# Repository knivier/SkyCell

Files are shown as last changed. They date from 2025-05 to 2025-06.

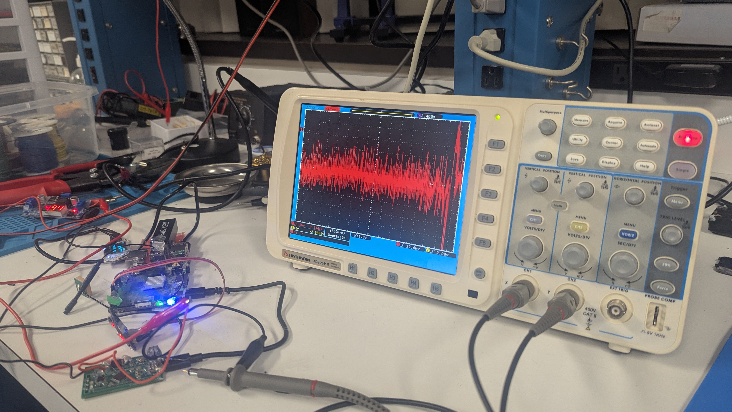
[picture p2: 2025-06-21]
project-images/prelaunch_night.jpg

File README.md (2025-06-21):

# SkyCell

#### The telecommunications solution on a balloon...for broke people alike.

This event was funded by the Apex event where we launched SkyCell on June 21st, 2025. It was the culmination of work from all of our teammates and over two months of planning (not to mention $400 in parts alone funded by Apex and the over $1200 in flight coverage as well).

## The Vision

Hurricanes, tornados, dust storms, and whatever other disasters wreck havoc on communications systems every year, risking lives. Technological dependency for communication has made telecommunication-based systems extremely important, and disasters pose a significant risk to that. 

Our team came up with the idea of SkyCell: A disaster-relief based telecommunications relief package/module that could be a backup incase primary communications systems fail.

## The Goals
1. Receive telemetry data in a JSON format from SkyCell when it is in the air
2. Be able to connect to SkyCell via a LoRA transceiver
3. Send and receive messages using SkyCell through meshtastic software 

## The Execution
### Planning
The initial plans were a basic CAD viewing of what SkyCell could look like along with a basic BOM. We knew we needed LoRA based communications, so we went with ESP-32s due to their relatively affordable prices (specifically, Heltec V3s). Pat also wanted to have SDR logging capabilities, so those components were added as well. We also got our own GPS module because we wanted SkyCell to be largely independent from the main balloon. 

For the main motherboard, we initially wanted to think about using a Raspberry Pi 5. However, it's a known fact that they aren't a great value, and a significantly better deal was a *Radxa Rock 5C*. This board was more efficient and more powerful than the RPi5 while also being cheaper (on amazon that is). 

For power, we initially thought about 4x AA batteries but later went with 8, then 6 for some redundancy. Energizer Li-Ion Ultimate's were chosen as Apex organizers mentioned they were one of the few AAs that supported as low as -40C temperatures. 

For software, we went with a modular design, choosing to implement features slowly as we coded our main board. Built in logging was very important as should SkyCell fail to send messages, we would want to see why. These were written on a local SD card in the R5C. 

We also wanted to implement a camera (you can see remnants of that in `code\kniv's testing`) and created a compression algorithm for that as well that could have sent images over LoRA theoretically. However, this was later cut out in the final planning stages due to the higher expenses.
### Building
The building stage took an additional two months. During this time, parts were coded, assembled, and soldered down. 
#### Launch Night Issues
When testing with battery power (attempting to send/receive messages on battery) and with using a DC current power supply (regulatable), we discovered that the DC buck converter was having issues catching up with 5V, especially when systems like GPS and radios started (see: `project-images\prelaunch_night.jpg`), which caused bootlock and SD card corruption issues. This led to us trying to give as much voltage to the R5C without frying it (we gave up to 5.2v on the DC-DC and supplied 12V at one point), and we also tried large capacitors (up to 10,000µF). We also tried using a custom DC-DC 5V stepdown from another 'Apexer' with no luck. We even used a oscilloscope (that was a new one) to find out voltage patterns and isolate the problem.

In the end, we needed to scratch the idea of having AA batteries and instead chose to have a power bank fitted. This would only give us up to 30min of time, but it was better than having a non-functional project as a whole. 

We also wanted to have some telemetry sensors like a BMP180 for barometric, altitude, and temperature, along with an AHT21 for humidity and more temperature. During the flight though, the BMP180 got fried and when the AHT21 was working, it was already too late to implement a UART based system to connect the Pico to the R5C.
### Launch Time 
The module was launched at around the afternoon and traveled for around two hours. We only received around 3-4 packets of data and were able to connect to the node quite far away (LoRA systems were set up back at the main site while the balloon was launched quite far north). 

## Review

### What parts would we use instead?
For starters, a significantly better DC-DC Buck Converter. The issues would have been fixed if we could give more power to the pi at certain points (ex at startup give the Pi 5V->5.5V->5V) so there was more startup power.

A BME280 would've also been a life saver as it integrates all the sensors we needed (BMP180 + AHT21) into one. 

Finally, although the ESP32s did pick up some transmissions, we only received an estimated <20% of total sent packets. Using a significantly longer antenna along with a GUI-based LoRA system (something like the *# LILYGO T-Deck Plus ESP32-S3 915Mhz LORA-89 SX1262 Ulbox GPS 2.8-inch Display TTGO*) would have likely increased efficiency. 
### What software choices would we do instead?
We should've sent packets more frequently and not tried to do so much in the beginning. In the end, many of our new attempts failed and made it a lot more worse for the stuff that should have been trivial. 

### Did we do what we set out to do?
We never sent out messages on the launch date because the balloon was travelling at 60m/s when we got disconnected (that's over 200kph). However, we did still connect to the node for a minute, and we also received ~mostly~ valid telemetry packets.

SkyCell was never meant to be a full project showcase 100% completed, it was rather a proposal or a proof of concept that it is possible over LoRA

If we were given an extra $200 (bringing the total budget to $600), it's likely that our project would have been a lot more polished, however we're happy that we got live data anyways.

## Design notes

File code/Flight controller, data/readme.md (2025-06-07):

flight recorder/controlling sensors, transmission, all important data - meddy

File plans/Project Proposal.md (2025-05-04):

SkyCell: Balloon-Based Disaster Relief Communication System Proposal
Meddy, Agniva, Sharon, Patricio 
1. Introduction
	Natural disasters, such as earthquakes and hurricanes cripple essential infrastructure, such as power and communication systems, leaving many communities and people in devastating conditions without any way to contact help. As reported by FEMA, in the aftermath of the 2017 Hurricane Maria, 95% of cell towers in Puerto Rico had become out of service. Restoring communication systems is crucial for coordinating rescue efforts and allowing survivors to call for help. We propose designing and testing a high-altitude balloon-borne cellular node as a rapid solution to re-establish cellular coverage in disaster zones. Balloons in the stratosphere can provide a wide area–of roughly 900 mile radius—line-of-sight coverage, allowing the payload to act as a cell tower. Major initiatives, such as Alphabet’s Loon project and SoftBank's trials of tethered balloons have validated this approach. Our team plans to build on these concepts while focusing on cost-effectiveness, user friendliness, allowing for affordability, ease of use, and optimal deployment time. The goal is to develop a 1 ft³ <0.75 lb payload that functions as a cell relay at ~100,000 ft altitude for 2–3 hours, allowing for emergency voice/SMS and/or data connectivity to mobile phones on the ground. By using open source cellular technology commercial off-the-shelf components, our system, called Skycell,  will effectively create a rapidly deployed micro cell tower in the sky. It will comply with all regulations and emphasize simplicity and safety.
2. Objectives
Restore Connectivity Quickly after disasters
Fit Small and Light so a single weather balloon can carry it.
Operate at 100,000 feet to cover a large area below
Use easy-to-build, open-source tools (like GSM and SDR) that our team can handle
3. Methodology
Phase 1: Design & Simulation
Finalize the system design through simulations and research. Budget calculations, GSM network configuration planning , and parts selection. We will use software tools (e.g. MATLAB or GNURadio simulations) to model the GSM coverage area and capacity. Milestone: Complete schematic of system, get any necessary experimental licenses (e.g. FCC STA or amateur call sign for telemetry). We will also design the ground module that will imitate a phone and test the connection on the ground.
Phase 2: Procurement & Bench Testing. 
Order all components per the BOM. Once parts arrive, perform bench tests: power on the Raspberry Pi (or similar) and install OpenBTS/YateBTS. Connect the LimeSDR and verify it can transmit a carrier and receive on the chosen band. We will test the BTS software with two test phones on the ground (at low power) to ensure calls/texts work in a small cell configuration. We’ll also measure the current draw of each module to validate the power budget. The RF amplifier will be tested with a signal generator to ensure it provides gain and is stable. Milestone: End-to-end call or SMS made via the system on the bench (with two phones connected through the BTS).
Phase 3: Integration
Assembling the components into the payload enclosure. Integrate sensors to log altitude and internal temperature during flight. The payload will be weighed and if overweight, figure out how to save weight. Once integrated, full system tests will be performed by attempting connections. We will verify the broadcasted network appears on phones and that one can place a call between two devices on the network (we’ll use an Asterisk PBX on the Pi or the built-in SIP functionality of OpenBTS to route a call). We’ll measure the RF output with a spectrum analyzer to ensure the filter and amplifier are doing their job . Milestone: Fully integrated payload passes a functional test and is ready for flight. 
High-Altitude Balloon Launch 
Conduct the full balloon launch, following FAA regulations for the launch. On launch day, the system will be powered on a few minutes before release and we’ll verify ground connection one last time. Once launched, the ground team will monitor the telemetry, tracking ascent rate, altitude, and attempt test calls as the balloon ascends. We expect the best connectivity at higher altitudes due to broader line-of-sight. We will also send a message from the balloon to test one-way alerting. We will continue to log data until landing. Milestone: Successful flight with at least one two-way communication achieved between ground unit andpayload. Safe recovery of payload.
After the flight, we will analyze logs: 
BTS logs (to see how many users connected, signal levels), sensor logs (temperature, battery voltage over time), and any user feedback (voice quality, range). We will prepare results demonstrating the coverage area achieved – e.g. mapping where connections were made. If any part of the system underperformed (battery died early, etc.), we propose solutions (like adding another cell, which we likely budgeted weight for). At this stage, we will also finalize the research report for dissemination. This includes the engineering findings and the potential impact on disaster communications – for instance, extrapolating how multiple such balloon relays could network to cover larger areas or provide mesh backhaul. We will emphasize the success metrics, such as how quickly it was deployed and how many calls it could support, linking back to the overarching goal of improving disaster response. Milestone: Completion of a comprehensive report and, if possible, a demonstration to stakeholders (e.g. a live demo for emergency management officials or at a research expo).

4. Risk Management
Signal Interference and Legal Compliance
 Operating radio systems at high altitudes poses potential risks of interfering with other services. We will fix this by using only approved frequency bands, low transmission power, and RF band-pass filters to minimize disruption.

Payload Weight Limitations
 The balloon payload must remain under 0.75 lbs. To manage this, we will use lightweight components, measure detailed weight checks, and remove anything nonessential.

Power System Failure
 Cold stratospheric temperatures can significantly reduce battery performance so we will insulate the battery, use heaters, and use batteries with proven cold-weather reliability, and possibly using solar. Backup systems in our software will allow maximum usage of all communication protocols by prioritizing certain systems as voltage levels continue to drop. 

Software Malfunction
 The base station software or payload could crash mid-flight. Ground testing will be conducted beforehand as well as automated scripts to restart or reboot the system if a failure is detected. Data from the payload will constantly be transmitted back to the base station.

Balloon Drift or Loss of Payload
The payload will include a GPS tracker with a radio link for real-time location updates, as well as mapping the balloon’s path in a 3d  viewer
7. Expected Outcomes
Demonstration of a Working Airborne GSM Network:
 The balloon payload will create a functional connection that connects to standard mobile phones for voice and SMS communication.

Successful Communication Testing During Flight:
 Real-time voice and SMS tests will be conducted from ground users connected through the balloon’s GSM relay.

Wide Area Coverage:
 From an altitude of approximately 100,000 feet, we expect signal coverage over a 30–50 km radius.

Proof of Concept for Disaster Use:
 The results will demonstrate that balloon-based cellular relays are feasible, fast to deploy, and effective in disaster scenarios.

Safe Recovery of Payload:
 With a parachute and GPS tracker, the payload will be safely recovered for data extraction and potential reuse.

8. Conclusion
This project presents a practical and innovative solution for restoring emergency communications in disaster-struck regions using a high-altitude balloon. By deploying a lightweight GSM base station into the stratosphere, we aim to reconnect isolated individuals using only the phones they already own. Our approach emphasizes affordability, portability, and ease of deployment. The outcome of this research will validate the potential for such systems to become standard tools in humanitarian response, empowering communities and saving lives when infrastructure fails.
9. References

https://arxiv.org/abs/2410.13977

https://www.theverge.com/2022/9/12/23349291/alphabet-google-project-loon-aalyria-lasers-communication

https://www.google.com/search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

https://scholar.google.com/scholar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

https://ieeexplore.ieee.org/abstract/document/10793319

https://link.springer.com/article/10.1007/s11235-019-00580-w

https://www.google.com/search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

https://ieeexplore.ieee.org/abstract/document/9899783

10. Appendices
CAD drawings and system schematics.

Detailed parts list (BOM) 

Calculations and simulations.
Appendix A: Acronyms
GSM – Global System for Mobile Communications

SDR – Software-Defined Radio

BTS – Base Transceiver Station

HAB – High-Altitude Balloon

EIRP – Effective Isotropic Radiated Power

LTE – Long-Term Evolution

STA – Special Temporary Authorization (FCC)

Appendix B: System Software
Raspberry Pi OS / DragonOS – Operating system for Raspberry Pi

OpenBTS / Osmocom – Open-source GSM base station software

Asterisk – Open-source telephony server (optional)

GNURadio – SDR interface and signal processing toolkit

Appendix C: Pre-Flight Checklist
Battery fully charged and secured

SDR, amplifier, and Raspberry Pi securely mounted

GSM software configured and tested

Antenna tuned and mounted downward

GPS and LoRa tracker activated

Balloon and parachute securely attached (to be done by deployment team)

Weather and airspace conditions verified (to be done by deployment team)
Software manual check systems for all sensor calibrations and detections

Appendix D: Regulatory References
FCC Part 97 & Part 15 – Rules for radio communication and unlicensed devices

ITU HAPS Regulations – Frequency use for high-altitude platforms

FAA Balloon Launch Guidelines – For amateur and research balloon flights (to be done by launch team)

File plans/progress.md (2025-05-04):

Pat: i got a basic link to work using two rfm95s and the adafruit circuit python library one is connected to a pi zero 2w the other to a pi pico but i think my setup isnt optimal for long range.
currently trying different settings to see if it works betterl.

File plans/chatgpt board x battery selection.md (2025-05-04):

Using Energizer Ultimate Lithium AA batteries is an excellent choice for high-altitude and low-temperature environments due to their superior performance in extreme conditions, especially in sub-zero temperatures. These batteries maintain a consistent voltage and are much more efficient at cold temperatures compared to regular alkalines or even NiMH batteries.
CONSIDER: The Feather M4 Express can run off 5V, but if the input voltage drops below 5V, the board may become unstable (redundancies!)
How to Power the Feather M4 Express with Lithium AA Batteries
Since Energizer Ultimate Lithium AA batteries provide 1.5V per cell and you’ll be using 3 or 4 batteries for your setup, here’s what you need to know:
3x AA (1.5V each) = 4.5V → Close to the Feather M4's recommended operating voltage (3.3V-5V).
4x AA (1.5V each) = 6V → This will need to be regulated to 5V to avoid damaging the board.
Powering Setup Options
3x AA (4.5V) Setup:

This setup is close to the 5V tolerance range of the Feather M4. However, it may be slightly unstable as the voltage can drop over time. You can use a low-dropout voltage regulator (LDO) to keep it steady.
Consider a boost converter to maintain a consistent 5V output as the voltage from the batteries decreases.
4x AA (6V) Setup:

This will definitely need a voltage regulator. A DC-DC buck converter can efficiently step down 6V to 5V or 3.3V, depending on your needs.
This setup ensures a stable power supply even as the batteries discharge.

Recommended Components for Power Regulation
Step-down (buck) converter: Converts 6V from 4x AA to 5V or 3.3V for stable operation. You can get a small, efficient DC-DC buck converter like the Pololu 5V Step-Down Voltage Regulator.
Low-dropout (LDO) voltage regulator: For a 3x AA setup, you can use an LDO that keeps the voltage around 5V.

Summary
Energizer Ultimate Lithium AA batteries (3x or 4x) are great for your high-altitude project.
Use a buck converter or LDO regulator to ensure consistent 5V or 3.3V output for your Feather M4 Express.
4x AA (6V) is a safer bet for voltage stability, but you’ll need to regulate the power.

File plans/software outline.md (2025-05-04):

Board - Main software hub
Should have logging capabilities to a 64GB+ microsd card 
Card should be rated to -40F-80F, also have a weather resistant type incase it gets dropped in water
Should have radio communications that do NOT interfere with the Apex communications
This should shut off as power lowers
All sensors should connect to board and report
Reporting should be in intervals, ex every 5s
Altitude (using barometers) with GPS tracking vs our dependants like gas type or solar input type 
Sensors should start shutting off as battery power decreases to avoid board failing

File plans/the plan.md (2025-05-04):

Test connection between a lora module on the ground and a lora module on the balloon
Make our own meshtastic nodes
Perform readings of noise levels at different frequencies and heights using and sdr
Test wifi halow performance (915mhz wifi)

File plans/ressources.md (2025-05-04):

Radiosondes
Website for tracking sondes and collecting them
https://sondehub.org/#!mt=Mapnik&mz=9&qm=3h&mc=44.17432,-79.80881 

Wiki
https://en.wikipedia.org/wiki/Radiosonde 

GPS
https://web.stanford.edu/group/scpnt/gpslab/pubs/papers/Reid_IONGNSS_2011_CommercialGPSintheStratosphere.pdf

https://wiki.dfrobot.com/50_Channel_GS407_Helical_GPS_Receiver__SKU_TEL0007_

Altitude Sensing

https://forums.adafruit.com/viewtopic.php?t=52141

https://www.rocketryforum.com/threads/above-100k-what-altimeter-has-been-used.121969/

Miscellaneous

https://www.instructables.com/Low-cost-Near-Space-Without-HAM-Radios-or-Cellphon/

https://www.adafruit.com/product/5046

Official Apex
Building requirements
https://apex.hackclub.com/resources/building

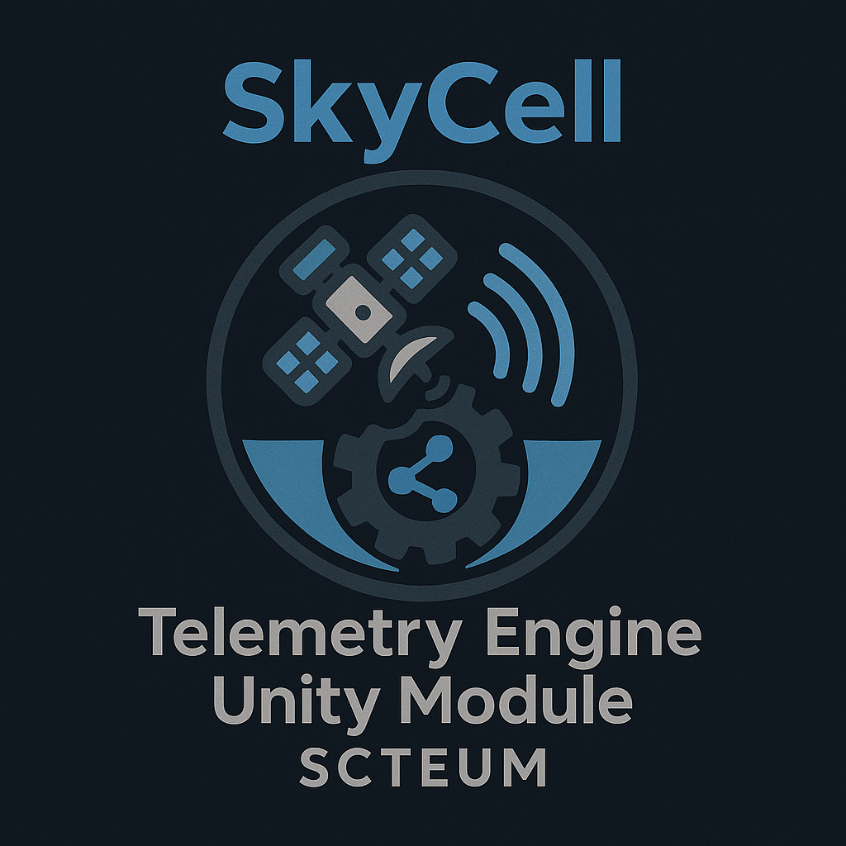
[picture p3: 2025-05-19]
code/skycell-hub/templates/SCTEUM.png

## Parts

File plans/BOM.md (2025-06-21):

## BOM for Apex

| Name | Price  | Source |
| --- | --- | --- |
| Pair of 915MHZ ESP Lora V3 Development board | $72.99 | Amazon |
| GPS Module Receiver Navigation NEO 6M with antennas high sensitivity | $25.99 | Amazon |
| RTL-SDR v5 SDR - NESDR Smart HF/VHF/UHF (100kHz - 1.75GHz) w/0.5PPM TCXO SMA Input & Alum. Enclosure - RTL2832U & R820T2 (R860)-Based Radio | $55.95 | Amazon |
| Wide Band Receive Scanner Antenna for Uniden SDS1000 BCD430P etc Radioshack Pro Whistler TRX-1 | $28.99 | Amazon |
| Battery Holder w/Wired battery clip standard snap connector (8xAA, Pair) | $10.99 | Amazon |
| FLY RC 10 Pairs T Plug Connectors Deans Style Male & Female w/20pk Heat Shrink Tubing | $10.99 | Amazon |
| Clear Electronic Grade Silicone | $19.00 | Amazon |
| 24 Piece HHeatsinks for Raspi 4 Model B | $8.99  | Amazon |
| Pair of (4x) AA Energizer Ultimate Lithium Batteries | $13.84 | Amazon |
| Easycargo 10pc Heatsink Kit Black Cooling GPU IC Chips etc | $7.32  | Amazon |
| Radxa Rock 5C | $75.00 | Amazon |
| Raspberry Pi Pico | $8.00  | Amazon |
| BMP 180 Sensor (6 Pack, Arduino Purposed) | $7.00  | Amazon |
| MakerFocus ESP32 LoRa V3 Development Board with 3000mAh Battery, Protective Case, 915MHz Antenna Integrated SX1262 | $32.99 | Amazon |
| AHT21 Sensor (x3) | $6.99  | Amazon |
| Micro USB to USB A Connector (Data) | $7.00  | Amazon |
| DC-DC Step Down Buck Converter (20->5V) | $10.00 | Amazon |
Total: $392.03

### Non-Apex Related Costs (w/Name):
- Raspberry Pi 5 ($80): Secondary device that should receive communications as well (Pat)
- Additional ESP 32 Handheld Heltec V3 ($30): Other LoRA device that connects to node so two devices can send and receive messages between each other (Pat)
- Soldering Iron, Solder, Flux, Wires, Breadboard, Jumper Cables, Solder Sucker, 3rd Hand for Soldering, Tip Thinner, Brass Tip Cleaner, etc ($200): Setup costs for soldering for a single person (Knivier) - Partially paid by Apex

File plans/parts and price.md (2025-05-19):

### energizer 8 AA lithium batteries 23$:
https://www.amazon.com/Energizer-Ultimate-Lithium-Battery-Package/dp/B00EAKP8S0?sr=8-8&th=1

### 4 AA battery holder 8$:
https://www.amazon.com/Onwon-Pieces-Battery-Holder-Storage/dp/B07M8RLXNL?sr=8-6&th=1

### microcontroller  $ x2:

### lora module  $ x2:

### u.fl (prob) 915 mhz antenna $ x2:

### gps $:

### wide band antenna:
https://www.amazon.ca/AEcreative-RTL-SDR-Wide-Band-RadioShack-Whistler/dp/B07GXZDSNK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

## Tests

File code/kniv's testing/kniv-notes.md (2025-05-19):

### Oki doki let's get started

#### What is this?

This is my testing space for projects I'm working on. Timestamps are below

5/11: I created some test beta code for esp-eye transmission stuff

ChatGPT guide below:
Great question, Knivier. Here's **exactly how to test the real ESP-EYE + LoRa system with `receiver.py`** in a full end-to-end setup. I’ll walk you through every step so nothing gets missed:

---

## 🧪 Testing the Real System: ESP Transmitter + PC Receiver

### 🧱 Setup Overview

| Component | Role |
| --- | --- |
| ESP-EYE | Captures JPEG, sends over LoRa |
| LoRa Receiver (e.g. T-Beam or Heltec) | Forwards raw packets to PC via USB serial |
| PC + Python | Runs `receiver.py` to reassemble images |

---

## ✅ Requirements

### On ESP-EYE:

* Your C++ code from earlier
* LoRa module (e.g., SX1276 breakout connected via SPI)
* Antenna attached

### On PC:

* LoRa receiver connected via USB (any LoRa board that supports serial output, like a Heltec/T-Beam/RAK)
* Python + `pyserial` and `Pillow`
* `receiver.py` script

---

## 🧰 Step-by-Step Guide

### 📸 1. Flash the ESP-EYE

1. Use the Arduino IDE or PlatformIO
2. Flash the `esp_camera + LoRa sender` code you already have
3. Use serial monitor to confirm it's sending chunks like:

   ```
   Sent frame 2 (37 chunks)
   ```

---

### 📡 2. Set Up the LoRa Receiver Board

**Goal:** Forward raw LoRa packets over USB serial

If you're using something like a Heltec or T-Beam, use this sketch:

```cpp
#include <SPI.h>
#include <LoRa.h>

#define LORA_SS 18
#define LORA_RST 14
#define LORA_DIO0 26

void setup() {
  Serial.begin(9600);
  LoRa.setPins(LORA_SS, LORA_RST, LORA_DIO0);

  if (!LoRa.begin(915E6)) {
    Serial.println("LoRa init failed");
    while (1);
  }

  Serial.println("LoRa Receiver");
}

void loop() {
  int packetSize = LoRa.parsePacket();
  if (packetSize > 0) {
    while (LoRa.available()) {
      Serial.write(LoRa.read());  // raw binary
    }
    Serial.write('\n');  // delimiter
  }
}
```

> ⚠️ You *must* use `Serial.write()` not `Serial.print()` — this ensures raw binary is passed to `receiver.py`.

---

### 🖥️ 3. Run `receiver.py` on Your PC

Update the port name to match your receiver board:

```python
PORT = '/dev/ttyUSB0'  # Linux
# PORT = 'COM4'        # Windows
```

Run it:

```bash
python receiver.py
```

If everything works, you'll see output like:

```
[✓] Complete frame 2, saving...
frame_2.jpg
```

And the images will appear in the folder!

---

## ✅ Verifying the Test

You’ve confirmed success when:

* The ESP serial monitor shows "Sent frame X"
* The receiver board lights up (DIO0 interrupt)
* `receiver.py` prints "Complete frame X"
* `.jpg` files appear and open cleanly

---

## 🔍 Optional Improvements

* Add checksum in packets for integrity
* Add display preview (Tkinter or OpenCV GUI)
* Add feedback from PC to ESP if frames fail

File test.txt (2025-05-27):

This is a test message to be written to a file.

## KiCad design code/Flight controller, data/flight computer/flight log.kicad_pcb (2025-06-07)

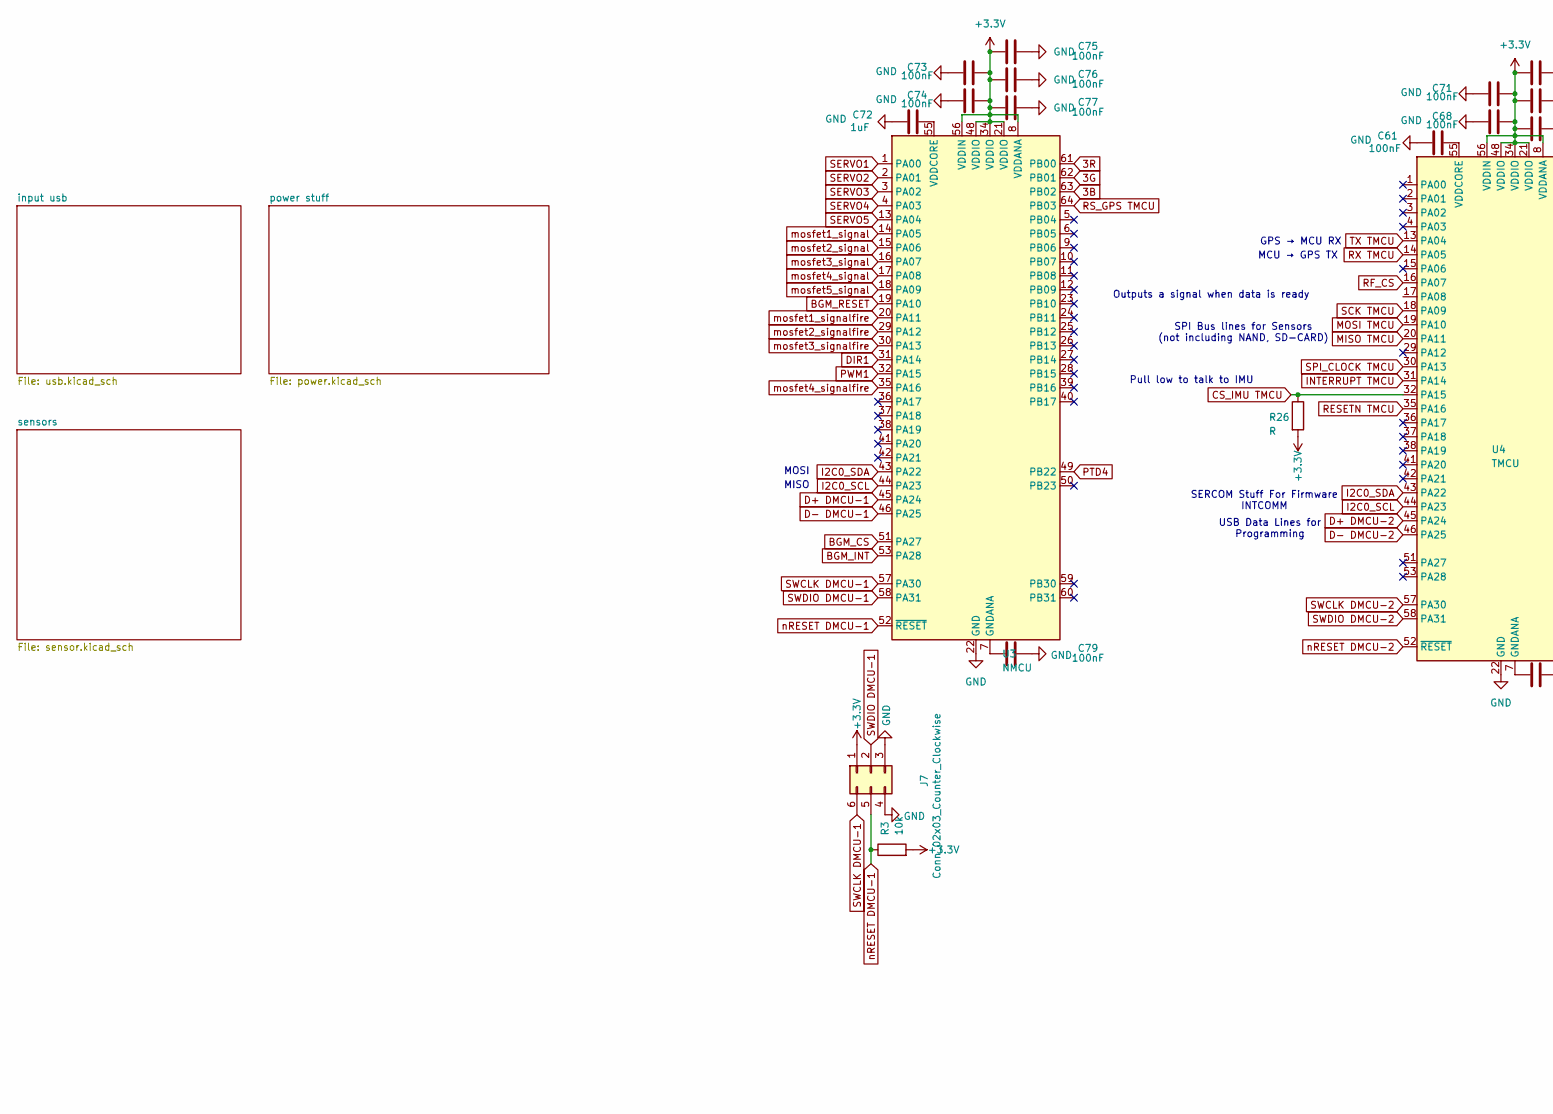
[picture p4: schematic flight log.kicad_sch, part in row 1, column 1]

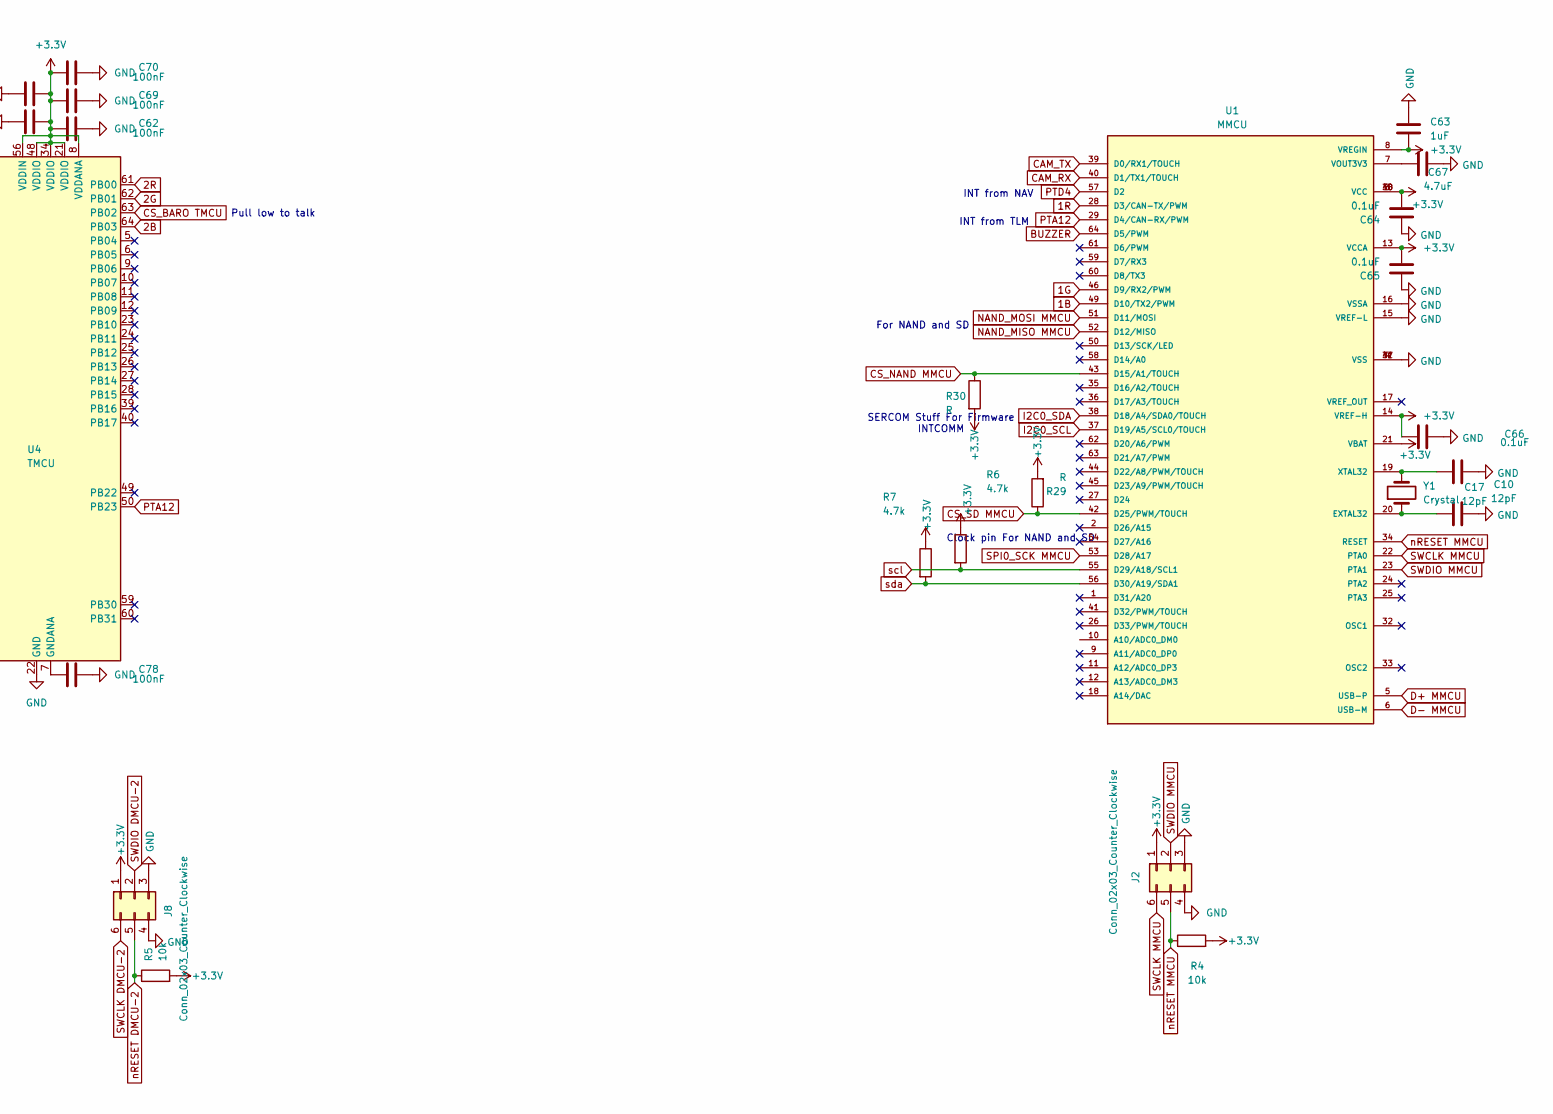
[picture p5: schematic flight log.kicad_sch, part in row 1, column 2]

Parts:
C10, C17: 12pF; C_0603_1608Metric
C61, C62, C68, C69, C70, C71, C73, C74, C75, C76, C77, C78, C79: 100nF; C_0603_1608Metric
C63, C72: 1uF; C_0603_1608Metric
C64, C65, C66: 0.1uF; C_0603_1608Metric
C67: 4.7uF; C_0603_1608Metric
J2, J7, J8: Conn_02x03_Counter_Clockwise; PinHeader_2x03_P2.54mm_Vertical
R3, R4, R5: 10k; R_0603_1608Metric
R6, R7: 4.7k; R_0603_1608Metric
R26, R29, R30: R; R_0603_1608Metric
U1: MMCU; QFP50P1200X1200X160-64N
U3: NMCU; TQFP-64_10x10mm_P0.5mm
U4: TMCU; TQFP-64_10x10mm_P0.5mm
Y1: Crystal; Crystal_AT310_D3.0mm_L10.0mm_Vertical

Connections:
1B: U1.49 (D10/TX2/PWM); also elsewhere on the board
1G: U1.46 (D9/RX2/PWM); also elsewhere on the board
1R: U1.28 (D3/CAN-TX/PWM); also elsewhere on the board
2B: U4.64 (PB03); also elsewhere on the board
2G: U4.62 (PB01); also elsewhere on the board
2R: U4.61 (PB00); also elsewhere on the board
3B: U3.63 (PB02); also elsewhere on the board
3G: U3.62 (PB01); also elsewhere on the board
3R: U3.61 (PB00); also elsewhere on the board
+3.3V: C62.2, C63.1, C64.1, C65.1, C66.1, C68.2, C69.2, C70.2, C71.2, C73.2, C74.2, C75.2, C76.2, C77.2, J2.1, J7.1, J8.1, R3.2, R4.2, R5.2, R6.1, R7.1, R26.2, R29.2, R30.2, U1.3 (VCC), U1.8 (VREGIN), U1.13 (VCCA), U1.14 (VREF-H), U1.21 (VBAT), U1.30 (VCC), U1.48 (VCC), U3.8 (VDDANA), U3.21 (VDDIO), U3.34 (VDDIO), U3.48 (VDDIO), U3.56 (VDDIN), U4.8 (VDDANA), U4.21 (VDDIO), U4.34 (VDDIO), U4.48 (VDDIO), U4.56 (VDDIN); also elsewhere on the board
BGM_CS: U3.51 (PA27); also elsewhere on the board
BGM_INT: U3.53 (PA28); also elsewhere on the board
BGM_RESET: U3.19 (PA10); also elsewhere on the board
BUZZER: U1.64 (D5/PWM); also elsewhere on the board
CAM_RX: U1.40 (D1/TX1/TOUCH); also elsewhere on the board
CAM_TX: U1.39 (D0/RX1/TOUCH); also elsewhere on the board
CS_BARO TMCU: U4.63 (PB02); also elsewhere on the board
CS_IMU TMCU: R26.1, U4.32 (PA15); also elsewhere on the board
CS_NAND MMCU: R30.1, U1.43 (D15/A1/TOUCH); also elsewhere on the board
CS_SD MMCU: R29.1, U1.42 (D25/PWM/TOUCH); also elsewhere on the board
D+ DMCU-1: U3.45 (PA24); also elsewhere on the board
D+ DMCU-2: U4.45 (PA24); also elsewhere on the board
D+ MMCU: U1.5 (USB-P); also elsewhere on the board
D- DMCU-1: U3.46 (PA25); also elsewhere on the board
D- DMCU-2: U4.46 (PA25); also elsewhere on the board
D- MMCU: U1.6 (USB-M); also elsewhere on the board
DIR1: U3.31 (PA14); also elsewhere on the board
GND: C10.2, C17.2, C61.1, C62.1, C63.2, C64.2, C65.2, C66.2, C67.2, C68.1, C69.1, C70.1, C71.1, C72.1, C73.1, C74.1, C75.1, C76.1, C77.1, C78.1, C79.1, J2.3, J2.4, J7.3, J7.4, J8.3, J8.4, U1.4 (VSS), U1.15 (VREF-L), U1.16 (VSSA), U1.31 (VSS), U1.47 (VSS), U3.22 (GND), U3.33 (GND), U3.47 (GND), U3.54 (GND), U4.22 (GND), U4.33 (GND), U4.47 (GND), U4.54 (GND); also elsewhere on the board
I2C0_SCL: U1.37 (D19/A5/SCL0/TOUCH), U3.44 (PA23), U4.44 (PA23); also elsewhere on the board
I2C0_SDA: U1.38 (D18/A4/SDA0/TOUCH), U3.43 (PA22), U4.43 (PA22); also elsewhere on the board
INTERRUPT TMCU: U4.31 (PA14); also elsewhere on the board
MISO TMCU: U4.20 (PA11); also elsewhere on the board
MOSI TMCU: U4.19 (PA10); also elsewhere on the board
NAND_MISO MMCU: U1.52 (D12/MISO); also elsewhere on the board
NAND_MOSI MMCU: U1.51 (D11/MOSI); also elsewhere on the board
unnamed: C17.1, U1.20 (EXTAL32), Y1.1
unnamed: C67.1, U1.7 (VOUT3V3)
unnamed: C10.1, U1.19 (XTAL32), Y1.2
unnamed: C79.2, U3.7 (GNDANA)
unnamed: C72.2, U3.55 (VDDCORE)
unnamed: C78.2, U4.7 (GNDANA)
unnamed: C61.2, U4.55 (VDDCORE)
PTA12: U1.29 (D4/CAN-RX/PWM), U4.50 (PB23)
PTD4: U1.57 (D2), U3.49 (PB22)
PWM1: U3.32 (PA15); also elsewhere on the board
RESETN TMCU: U4.35 (PA16)
RF_CS: U4.16 (PA07); also elsewhere on the board
RS_GPS TMCU: U3.64 (PB03); also elsewhere on the board
RX TMCU: U4.14 (PA05); also elsewhere on the board
SCK TMCU: U4.18 (PA09); also elsewhere on the board
SERVO1: U3.1 (PA00); also elsewhere on the board
SERVO2: U3.2 (PA01); also elsewhere on the board
SERVO3: U3.3 (PA02); also elsewhere on the board
SERVO4: U3.4 (PA03); also elsewhere on the board
SERVO5: U3.13 (PA04); also elsewhere on the board
SPI0_SCK MMCU: U1.53 (D28/A17); also elsewhere on the board
SPI_CLOCK TMCU: U4.30 (PA13); also elsewhere on the board
SWCLK DMCU-1: J7.6, U3.57 (PA30); also elsewhere on the board
SWCLK DMCU-2: J8.6, U4.57 (PA30)
SWCLK MMCU: J2.6, U1.22 (PTA0)
SWDIO DMCU-1: J7.2, U3.58 (PA31)
SWDIO DMCU-2: J8.2, U4.58 (PA31)
SWDIO MMCU: J2.2, U1.23 (PTA1)
TX TMCU: U4.13 (PA04); also elsewhere on the board
mosfet1_signal: U3.14 (PA05); also elsewhere on the board
mosfet1_signalfire: U3.20 (PA11); also elsewhere on the board
mosfet2_signal: U3.15 (PA06); also elsewhere on the board
mosfet2_signalfire: U3.29 (PA12); also elsewhere on the board
mosfet3_signal: U3.16 (PA07); also elsewhere on the board
mosfet3_signalfire: U3.30 (PA13)
mosfet4_signal: U3.17 (PA08); also elsewhere on the board
mosfet4_signalfire: U3.35 (PA16)
mosfet5_signal: U3.18 (PA09); also elsewhere on the board
nRESET DMCU-1: J7.5, R3.1, U3.52 (~RESET)
nRESET DMCU-2: J8.5, R5.1, U4.52 (~RESET)
nRESET MMCU: J2.5, R4.1, U1.34 (RESET)
scl: R6.2, U1.55 (D29/A18/SCL1)
sda: R7.2, U1.56 (D30/A19/SDA1)

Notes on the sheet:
SERCOM Stuff For Firmware INTCOMM
For NAND and SD
Pull low to talk to IMU
INT from TLM
Pull low to talk
GPS → MCU RX
Clock pin For NAND and SD
MCU → GPS TX
Outputs a signal when data is ready
MOSI
INT from NAV
USB Data Lines for Programming
SPI Bus lines for Sensors (not including NAND, SD-CARD)
MISO

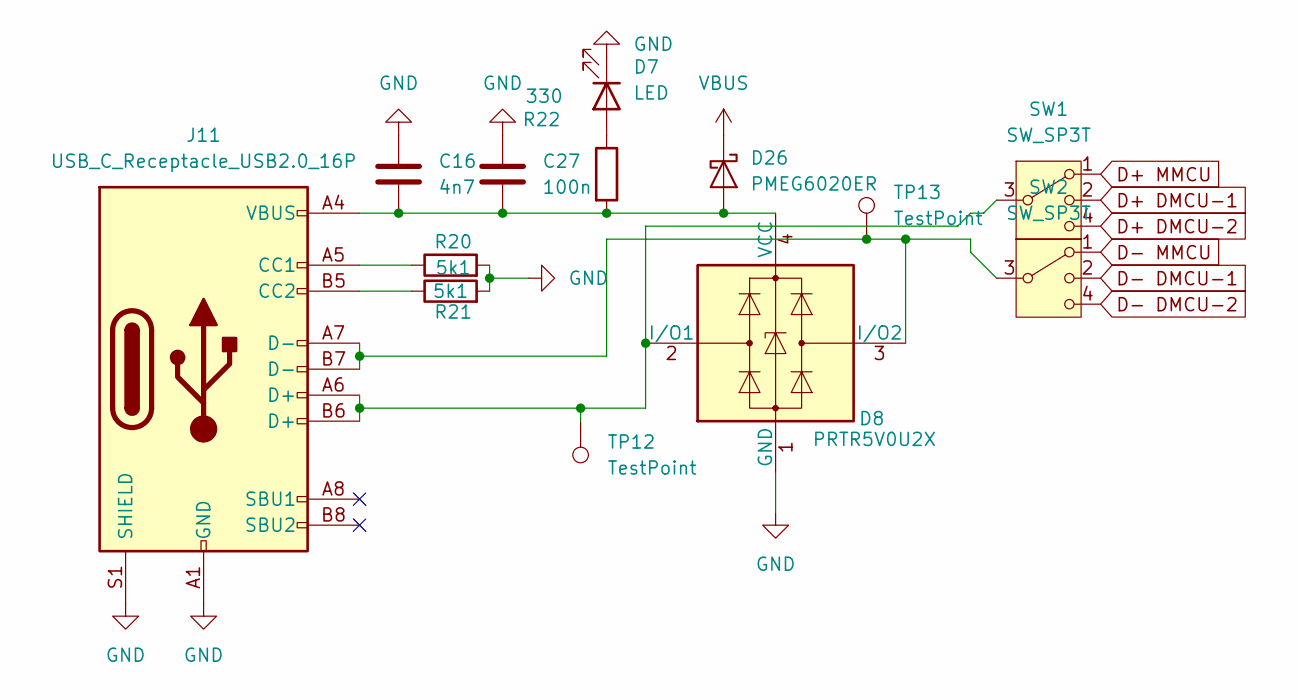
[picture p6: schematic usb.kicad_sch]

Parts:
C16: 4n7; C_0603_1608Metric
C27: 100n; C_0603_1608Metric
D7: LED; LED_0603_1608Metric
D8: PRTR5V0U2X; SOT-143
D26: PMEG6020ER; Nexperia_CFP3_SOD-123W
J11: USB_C_Receptacle_USB2.0_16P; USB_C_Receptacle_GCT_USB4105-xx-A_16P_TopMnt_Horizontal
R20, R21: 5k1; R_0603_1608Metric
R22: 330; R_0603_1608Metric
SW1, SW2: SW_SP3T; SW_NR01103ANG13-1C
TP12, TP13: TestPoint; TestPoint_Pad_1.0x1.0mm

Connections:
D+ DMCU-1: SW1.2; also elsewhere on the board
D+ DMCU-2: SW1.4; also elsewhere on the board
D+ MMCU: SW1.1; also elsewhere on the board
D- DMCU-1: SW2.2; also elsewhere on the board
D- DMCU-2: SW2.4; also elsewhere on the board
D- MMCU: SW2.1; also elsewhere on the board
GND: C16.1, C27.1, D7.1 (K), D8.1 (GND), J11.A1 (GND), J11.A12 (GND), J11.B1 (GND), J11.B12 (GND), J11.S1 (SHIELD), R20.2, R21.2; also elsewhere on the board
unnamed: D7.2 (A), R22.1
unnamed: D8.2 (I/O1), J11.A6 (D+), J11.B6 (D+), SW1.3, TP12.1
unnamed: D8.3 (I/O2), J11.A7 (D-), J11.B7 (D-), SW2.3, TP13.1
unnamed: C16.2, C27.2, D8.4 (VCC), D26.2 (A), J11.A4 (VBUS), J11.A9 (VBUS), J11.B4 (VBUS), J11.B9 (VBUS), R22.2
unnamed: J11.A5 (CC1), R20.1
unnamed: J11.B5 (CC2), R21.1
VBUS: D26.1 (K); also elsewhere on the board

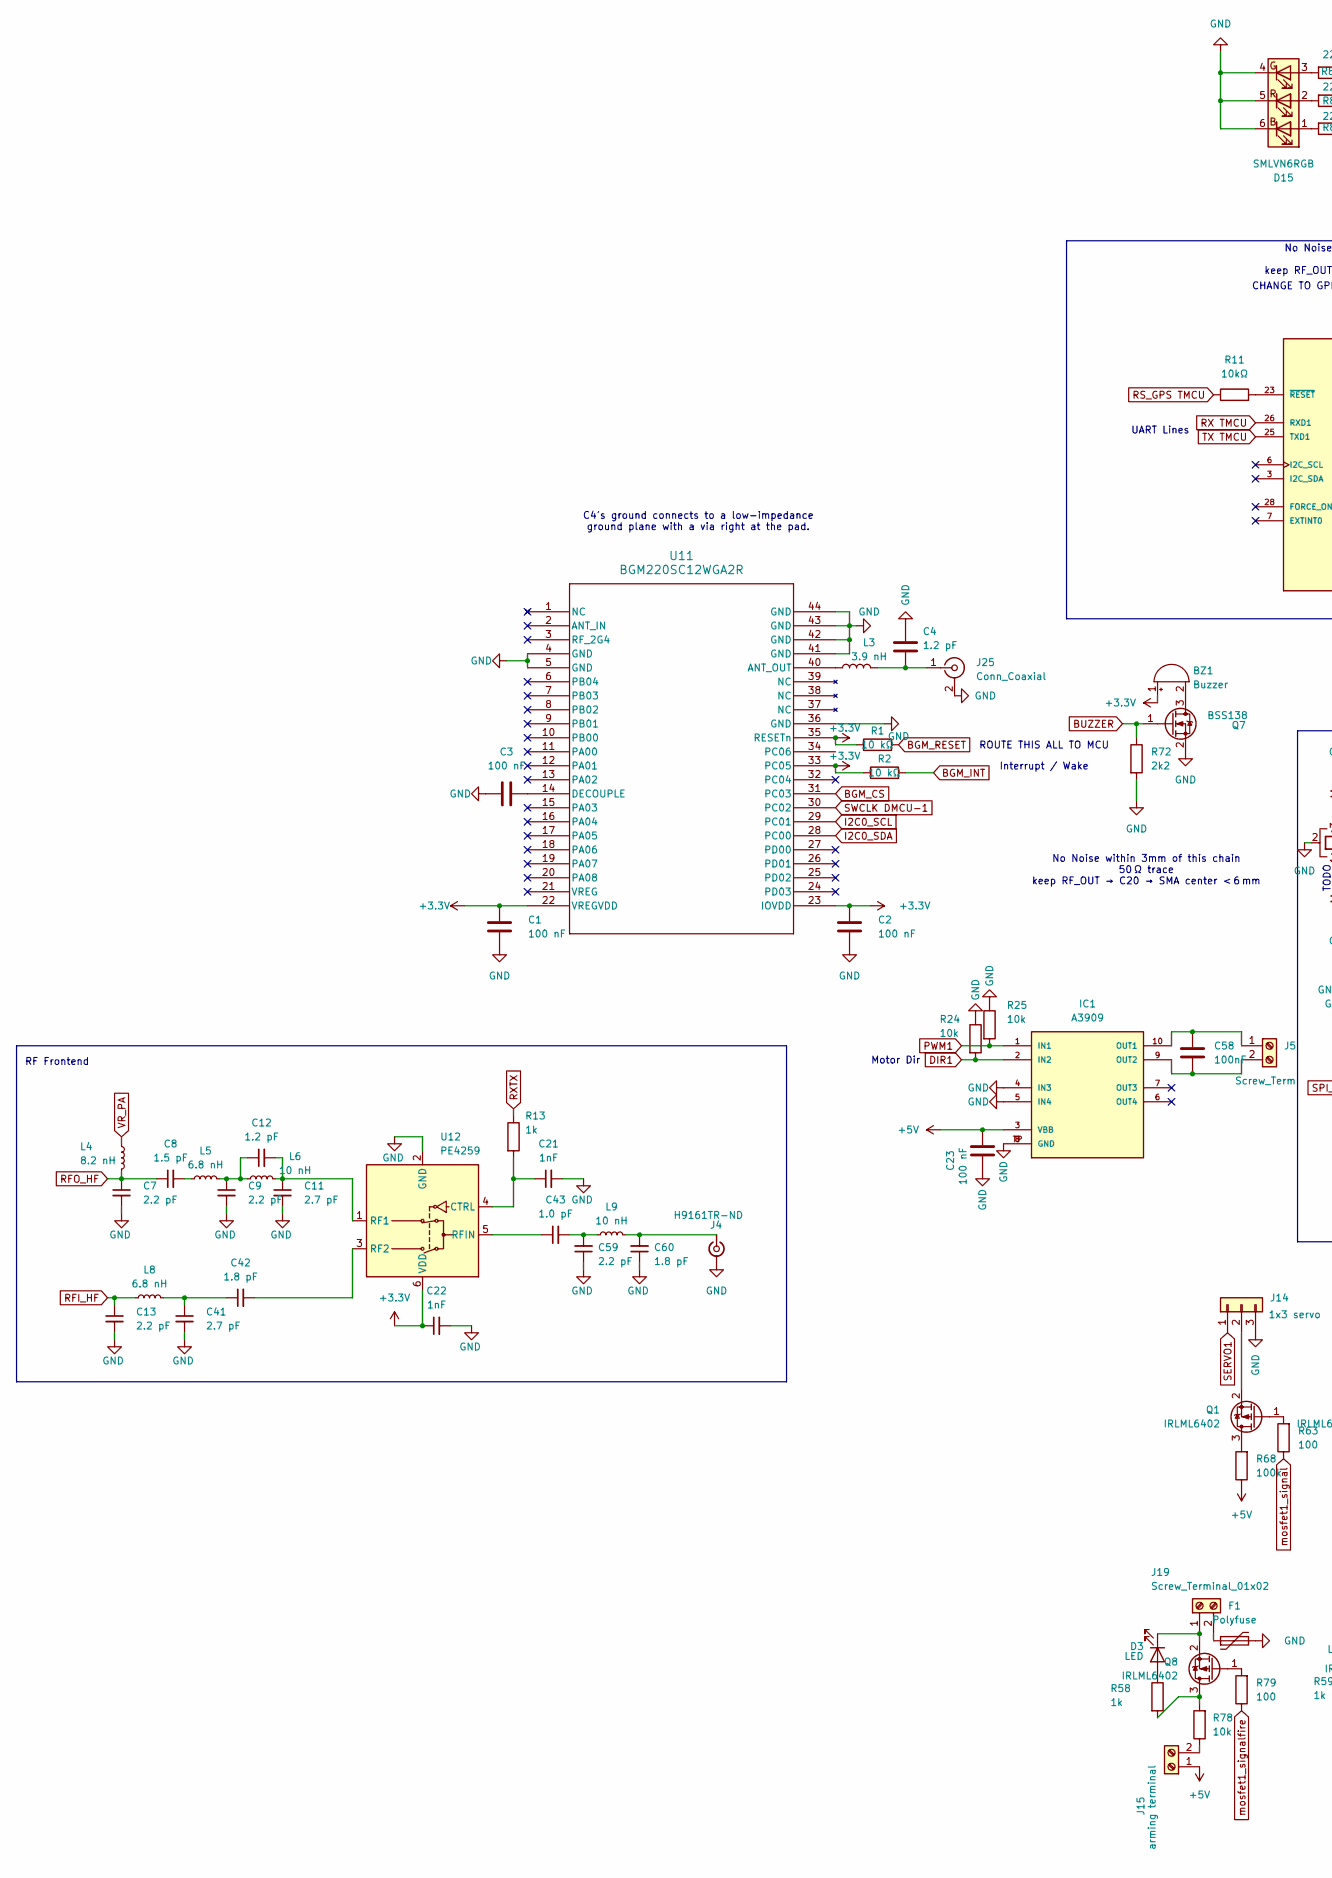
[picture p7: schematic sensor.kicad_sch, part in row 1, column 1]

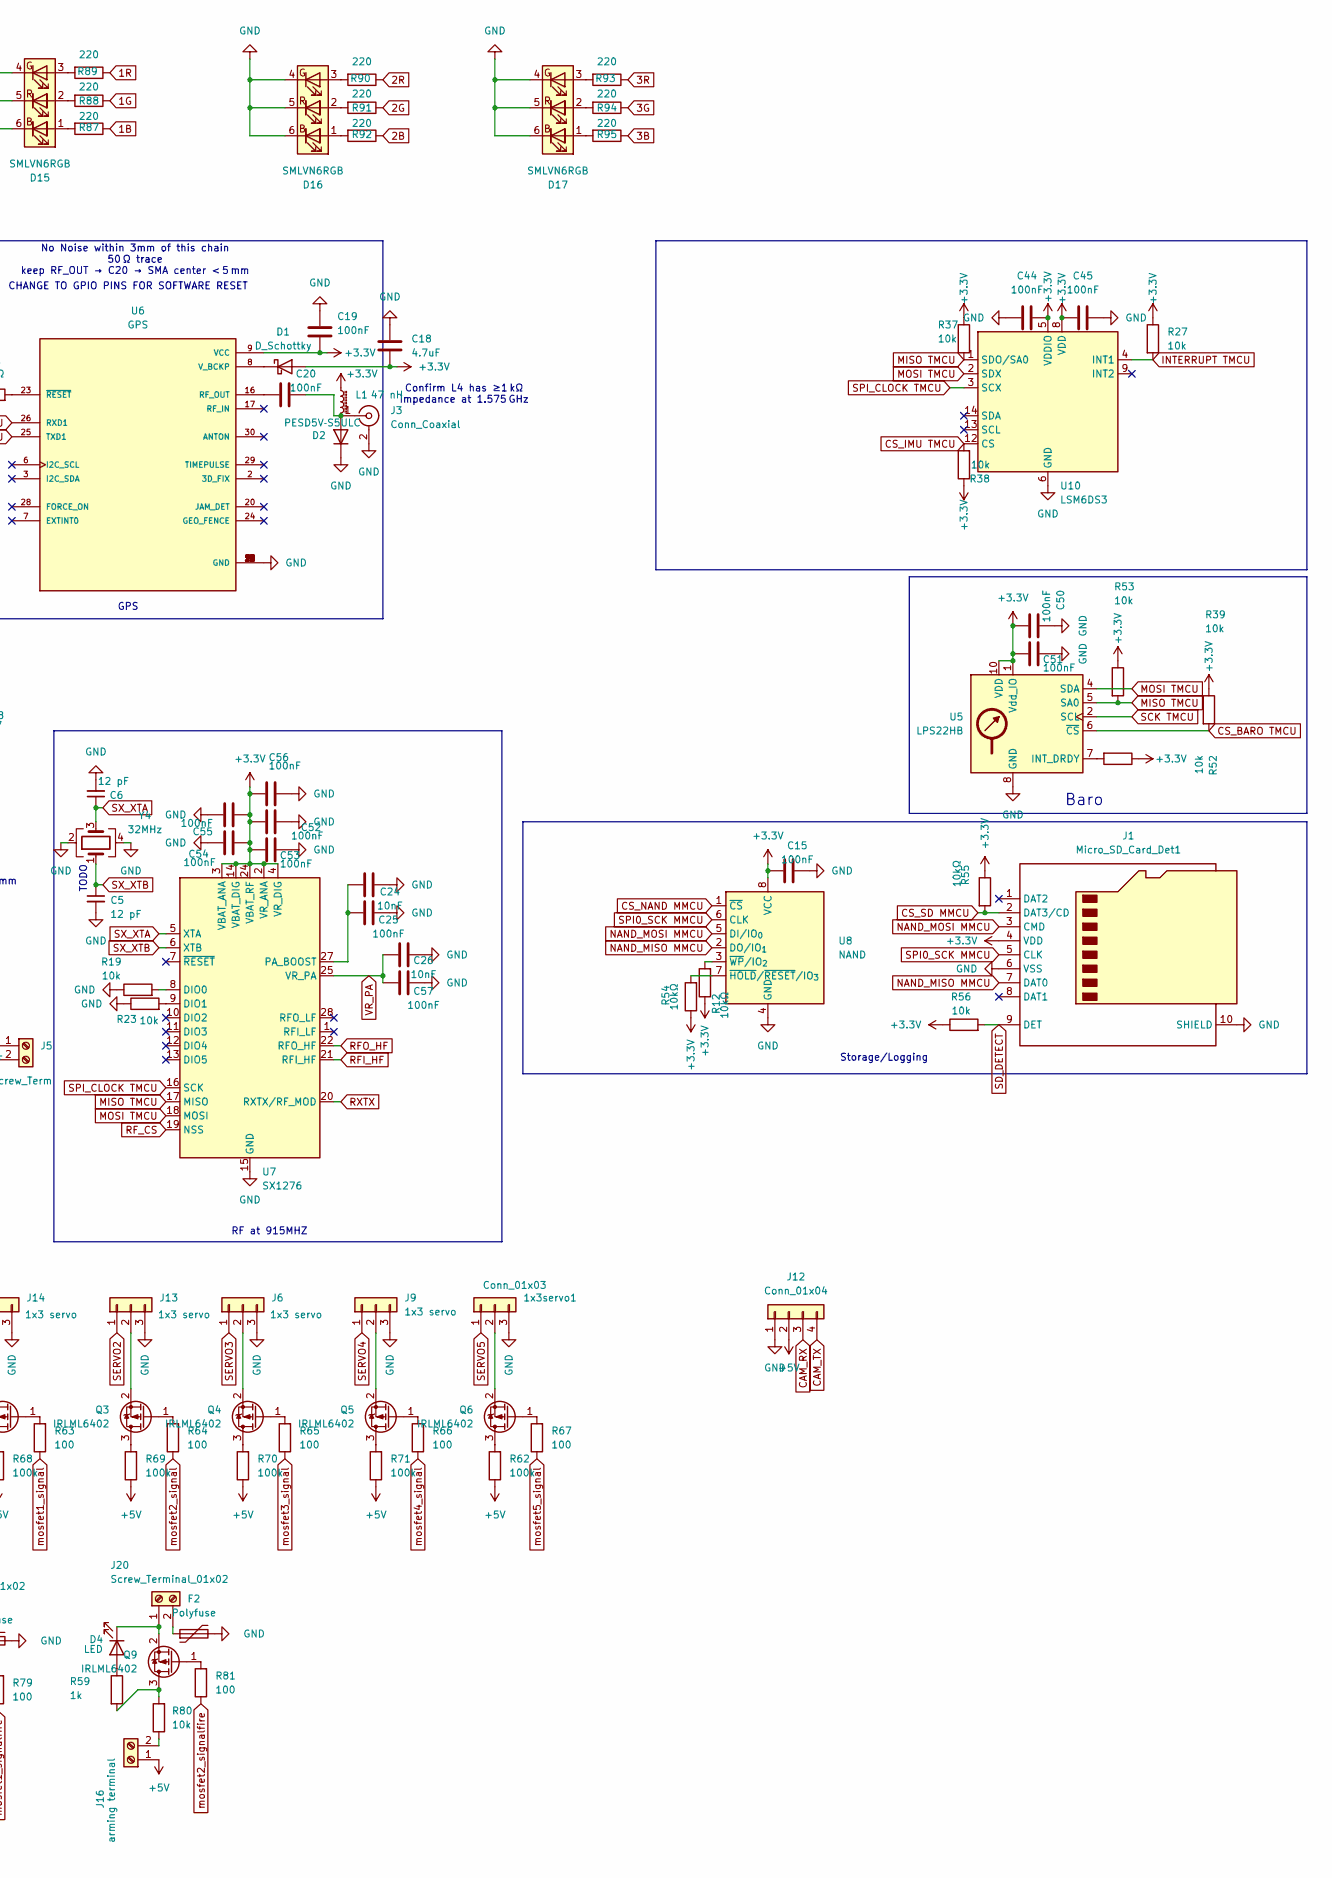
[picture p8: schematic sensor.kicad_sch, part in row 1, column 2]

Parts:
1x3servo1: Conn_01x03; PinHeader_1x03_P2.54mm_Vertical
BZ1: Buzzer; MagneticBuzzer_PUI_AT-0927-TT-6-R
C1, C2, C3, C23: 100 nF; C_0603_1608Metric
C4, C12: 1.2 pF; C_0603_1608Metric
C5, C6: 12 pF; C_0603_1608Metric
C7, C9, C13, C59: 2.2 pF; C_0603_1608Metric
C8: 1.5 pF; C_0603_1608Metric
C11, C41: 2.7 pF; C_0603_1608Metric
C15, C19, C20, C25, C44, C45, C50, C51, C52, C53, C54, C55, C56, C57, C58: 100nF; C_0603_1608Metric
C18: 4.7uF; C_0603_1608Metric
C21, C22: 1nF; C_0603_1608Metric
C24, C26: 10nF; C_0603_1608Metric
C42, C60: 1.8 pF; C_0603_1608Metric
C43: 1.0 pF; C_0603_1608Metric
D1: D_Schottky; D_0603_1608Metric
D2: PESD5V‑S5ULC; D_0603_1608Metric
D3, D4: LED; LED_0603_1608Metric
D15, D16, D17: SMLVN6RGB; LED_ROHM_SMLVN6
F1, F2: Polyfuse; Fuse_0603_1608Metric
IC1: A3909; MSOP10-PAD
J1: Micro_SD_Card_Det1; microSD_HC_Hirose_DM3D-SF
J3, J25: Conn_Coaxial; LPRS_SMA_CONNECTOR
J4: H9161TR-ND; HRS_U.FL-R-SMT_01_
J5: Screw_Term; TerminalBlock_Phoenix_MPT-0,5-2-2.54_1x02_P2.54mm_Horizontal
J6, J9, J13, J14: 1x3 servo; PinHeader_1x03_P2.54mm_Vertical
J12: Conn_01x04; PinHeader_1x04_P2.54mm_Vertical
J15, J16: arming terminal; TerminalBlock_Phoenix_MPT-0,5-2-2.54_1x02_P2.54mm_Horizontal
J19, J20: Screw_Terminal_01x02; TerminalBlock_Phoenix_MPT-0,5-2-2.54_1x02_P2.54mm_Horizontal
L1: 47 nH; L_0603_1608Metric
L3: 3.9 nH; L_0603_1608Metric
L4: 8.2 nH; L_0603_1608Metric
L5, L8: 6.8 nH; L_0603_1608Metric
L6, L9: 10 nH; L_0603_1608Metric
Q1, Q3, Q4, Q5, Q6, Q8, Q9: IRLML6402; SOT-23
Q7: BSS138; SOT-23
R1, R2: 10 kΩ; R_0603_1608Metric
R11, R12, R54, R55: 10kΩ; R_0603_1608Metric
R13, R58, R59: 1k; R_0603_1608Metric
R19, R23, R24, R25, R27, R37, R38, R39, R52, R53, R56, R78, R80: 10k; R_0603_1608Metric
R62, R68, R69, R70, R71: 100k; R_0603_1608Metric
R63, R64, R65, R66, R67, R79, R81: 100; R_0603_1608Metric
R72: 2k2; R_0603_1608Metric
R87, R88, R89, R90, R91, R92, R93, R94, R95: 220; R_0603_1608Metric
U5: LPS22HB; ST_HLGA-10_2x2mm_P0.5mm_LayoutBorder3x2y
U6: GPS; Quectel_L96; DigiKey_Part_Number 2958-L96-M33TR-ND
U7: SX1276; QFN-28-1EP_6x6mm_P0.65mm_EP4.8x4.8mm
U8: NAND; SOIC-8_5.3x5.3mm_P1.27mm
U10: LSM6DS3; LGA-14_3x2.5mm_P0.5mm_LayoutBorder3x4y
U11: BGM220SC12WGA2R
U12: PE4259; SOT-363_SC-70-6
Y4: 32MHz; Crystal_SMD_Abracon_ABM10-4Pin_2.5x2.0mm

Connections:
1B: R87.1; also elsewhere on the board
1G: R88.1; also elsewhere on the board
1R: R89.1; also elsewhere on the board
2B: R92.1; also elsewhere on the board
2G: R91.1; also elsewhere on the board
2R: R90.1; also elsewhere on the board
3B: R95.1; also elsewhere on the board
3G: R94.1; also elsewhere on the board
3R: R93.1; also elsewhere on the board
+3.3V: BZ1.1 (+), C1.2, C2.2, C15.1, C18.2, C19.2, C22.1, C44.2, C45.2, C50.2, C51.2, C52.2, C53.2, C54.2, C55.2, C56.2, D1.2 (A), J1.4 (VDD), L1.1, R1.1, R2.1, R12.1, R27.1, R37.1, R38.1, R39.1, R52.1, R53.1, R54.1, R55.1, R56.1, U5.1 (Vdd_IO), U5.10 (VDD), U6.9 (VCC), U7.2 (VR_ANA), U7.3 (VBAT_ANA), U7.4 (VR_DIG), U7.14 (VBAT_DIG), U7.24 (VBAT_RF), U8.8 (VCC), U10.5 (VDDIO), U10.8 (VDD), U11.22 (VREGVDD), U11.23 (IOVDD), U11.33 (PC05), U11.35 (RESETn), U12.6 (VDD); also elsewhere on the board
+5V: C23.2, IC1.3 (VBB), J12.2, J15.1, J16.1, R62.1, R68.1, R69.1, R70.1, R71.1; also elsewhere on the board
BGM_CS: U11.31 (PC03); also elsewhere on the board
BGM_INT: R2.2; also elsewhere on the board
BGM_RESET: R1.2; also elsewhere on the board
BUZZER: Q7.1 (G), R72.1; also elsewhere on the board
CAM_RX: J12.3; also elsewhere on the board
CAM_TX: J12.4; also elsewhere on the board
CS_BARO TMCU: R39.2, U5.6 (~CS); also elsewhere on the board
CS_IMU TMCU: R38.2, U10.12 (CS); also elsewhere on the board
CS_NAND MMCU: U8.1 (~CS); also elsewhere on the board
CS_SD MMCU: J1.2 (DAT3/CD), R55.2; also elsewhere on the board
DIR1: IC1.2 (IN2), R24.2; also elsewhere on the board
GND: 1x3servo1.3, C1.1, C2.1, C3.1, C4.1, C5.2, C6.2, C7.2, C9.2, C11.2, C13.2, C15.2, C18.1, C19.1, C21.2, C22.2, C23.1, C24.2, C25.2, C26.2, C41.2, C44.1, C45.1, C50.1, C51.1, C52.1, C53.1, C54.1, C55.1, C56.1, C57.2, C59.1, C60.1, D2.1 (K), D15.4 (GK), D15.5 (RK), D15.6 (BK), D16.4 (GK), D16.5 (RK), D16.6 (BK), D17.4 (GK), D17.5 (RK), D17.6 (BK), F1.2, F2.2, IC1.4 (IN3), IC1.5 (IN4), IC1.8 (GND), IC1.TP (GND), J1.6 (VSS), J1.10 (SHIELD), J3.2 (Ext), J3.G1, J3.G2, J3.G3, J3.G4, J4.2 (Ext), J6.3, J9.3, J12.1, J13.3, J14.3, J25.2 (Ext), J25.G1, J25.G2, J25.G3, J25.G4, Q7.2 (S), R19.1, R23.1, R24.1, R25.1, R72.2, U5.3 (GND), U5.8 (GND), U5.9 (GND), U6.4 (GND), U6.5 (GND), U6.10 (GND), U6.11 (GND), U6.12 (GND), U6.13 (GND), U6.14 (GND), U6.15 (GND), U6.18 (GND), U6.19 (GND), U6.21 (GND), U6.22 (GND), U6.27 (GND), U6.31 (GND), U7.15 (GND), U7.23 (GND), U7.26 (GND), U7.29 (GND), U8.4 (GND), U10.6 (GND), U10.7 (GND), U11.4 (GND), U11.5 (GND), U11.36 (GND), U11.41 (GND), U11.42 (GND), U11.43 (GND), U11.44 (GND), U12.2 (GND), Y4.2, Y4.4; also elsewhere on the board
I2C0_SCL: U11.29 (PC01); also elsewhere on the board
I2C0_SDA: U11.28 (PC00); also elsewhere on the board
INTERRUPT TMCU: R27.2, U10.4 (INT1); also elsewhere on the board
MISO TMCU: R37.2, R53.2, U5.5 (SA0), U7.17 (MISO), U10.1 (SDO/SA0); also elsewhere on the board
MOSI TMCU: U5.4 (SDA), U7.18 (MOSI), U10.2 (SDX); also elsewhere on the board
NAND_MISO MMCU: J1.7 (DAT0), U8.2 (DO/IO_{1}); also elsewhere on the board
NAND_MOSI MMCU: J1.3 (CMD), U8.5 (DI/IO_{0}); also elsewhere on the board
unnamed: 1x3servo1.2, Q6.2 (S)
unnamed: BZ1.2 (-), Q7.3 (D)
unnamed: C8.2, L5.1
unnamed: C9.1, C12.1, L5.2, L6.1
unnamed: C41.1, C42.1, L8.2
unnamed: C43.2, C59.2, L9.1
unnamed: D1.1 (K), U6.8 (V_BCKP)
unnamed: C20.1, D2.2 (A), J3.1 (In), L1.2
unnamed: D3.2 (A), R58.1
unnamed: D3.1 (K), J19.1, Q8.2 (S)
unnamed: D4.2 (A), R59.1
unnamed: D4.1 (K), J20.1, Q9.2 (S)
unnamed: D15.1 (BA), R87.2
unnamed: D15.3 (GA), R89.2
unnamed: D15.2 (RA), R88.2
unnamed: D16.1 (BA), R92.2
unnamed: D16.3 (GA), R90.2
unnamed: D16.2 (RA), R91.2
unnamed: D17.1 (BA), R95.2
unnamed: D17.3 (GA), R93.2
unnamed: D17.2 (RA), R94.2
unnamed: C58.1, IC1.10 (OUT1), J5.1
unnamed: C58.2, IC1.9 (OUT2), J5.2
unnamed: C60.2, J4.1 (In), L9.2
unnamed: J6.2, Q4.2 (S)
unnamed: J9.2, Q5.2 (S)
unnamed: J13.2, Q3.2 (S)
unnamed: J14.2, Q1.2 (S)
unnamed: J15.2, R78.1
unnamed: J16.2, R80.1
unnamed: F1.1, J19.2
unnamed: F2.1, J20.2
unnamed: C4.2, J25.1 (In), L3.2
unnamed: Q1.3 (D), R68.2
unnamed: Q1.1 (G), R63.2
unnamed: Q3.3 (D), R69.2
unnamed: Q3.1 (G), R64.2
unnamed: Q4.3 (D), R70.2
unnamed: Q4.1 (G), R65.2
unnamed: Q5.3 (D), R71.2
unnamed: Q5.1 (G), R66.2
unnamed: Q6.3 (D), R62.2
unnamed: Q6.1 (G), R67.2
unnamed: Q8.3 (D), R58.2, R78.2
unnamed: Q8.1 (G), R79.2
unnamed: Q9.3 (D), R59.2, R80.2
unnamed: Q9.1 (G), R81.2
unnamed: R52.2, U5.7 (INT_DRDY)
unnamed: C20.2, U6.16 (RF_OUT)
unnamed: R11.2, U6.23 (~RESET)
unnamed: R19.2, U7.8 (DIO0)
unnamed: R23.2, U7.9 (DIO1)
unnamed: C24.1, C25.1, U7.27 (PA_BOOST)
unnamed: R54.2, U8.7 (~HOLD/~RESET/IO_{3})
unnamed: R12.2, U8.3 (~WP/IO_{2})
unnamed: L3.1, U11.40 (ANT_OUT)
unnamed: C3.2, U11.14 (DECOUPLE)
unnamed: C21.1, R13.2, U12.4 (CTRL)
unnamed: C11.1, C12.2, L6.2, U12.1 (RF1)
unnamed: C42.2, U12.3 (RF2)
unnamed: C43.1, U12.5 (RFIN)
PWM1: IC1.1 (IN1), R25.2; also elsewhere on the board
RFI_HF: C13.1, L8.1, U7.21 (RFI_HF)
RFO_HF: C7.1, C8.1, L4.2, U7.22 (RFO_HF)
RF_CS: U7.19 (NSS); also elsewhere on the board
RS_GPS TMCU: R11.1; also elsewhere on the board
RX TMCU: U6.26 (RXD1); also elsewhere on the board
RXTX: R13.1, U7.20 (RXTX/RF_MOD)
SCK TMCU: U5.2 (SCL); also elsewhere on the board
SD_DETECT: J1.9 (DET), R56.2
SERVO1: J14.1; also elsewhere on the board
SERVO2: J13.1; also elsewhere on the board
SERVO3: J6.1; also elsewhere on the board
SERVO4: J9.1; also elsewhere on the board
SERVO5: 1x3servo1.1; also elsewhere on the board
SPI0_SCK MMCU: J1.5 (CLK), U8.6 (CLK); also elsewhere on the board
SPI_CLOCK TMCU: U7.16 (SCK), U10.3 (SCX); also elsewhere on the board
SWCLK DMCU-1: U11.30 (PC02); also elsewhere on the board
SX_XTA: C6.1, U7.5 (XTA), Y4.3
SX_XTB: C5.1, U7.6 (XTB), Y4.1
TX TMCU: U6.25 (TXD1); also elsewhere on the board
VR_PA: C26.1, C57.1, L4.1, U7.25 (VR_PA)
mosfet1_signal: R63.1; also elsewhere on the board
mosfet1_signalfire: R79.1; also elsewhere on the board
mosfet2_signal: R64.1; also elsewhere on the board
mosfet2_signalfire: R81.1; also elsewhere on the board
mosfet3_signal: R65.1; also elsewhere on the board
mosfet4_signal: R66.1; also elsewhere on the board
mosfet5_signal: R67.1; also elsewhere on the board

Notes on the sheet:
Motor Dir
RF Frontend
TODO
GPS
UART Lines
C4's ground connects to a low-impedance ground plane with a via right at the pad.
Storage/Logging
CHANGE TO GPIO PINS FOR SOFTWARE RESET
ROUTE THIS ALL TO MCU
Baro
Confirm L4 has ≥1 kΩ impedance at 1.575 GHz
Interrupt / Wake
No Noise within 3mm of this chain 50 Ω trace keep RF_OUT → C20 → SMA center < 6 mm
RF at 915MHZ
No Noise within 3mm of this chain 50 Ω trace keep RF_OUT → C20 → SMA center < 5 mm

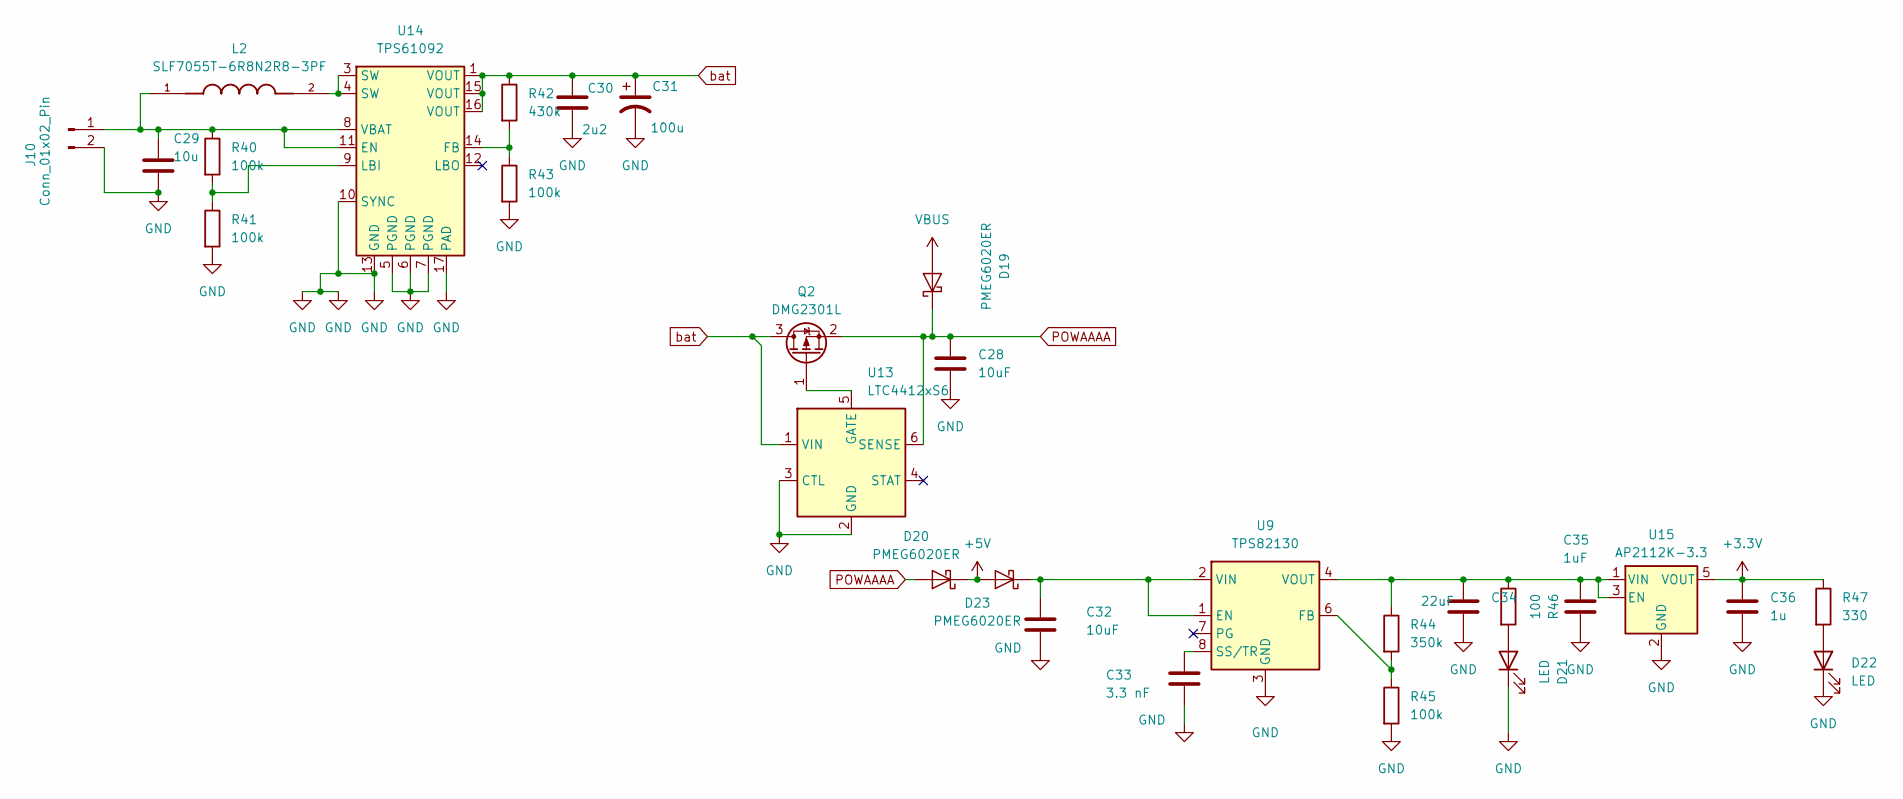
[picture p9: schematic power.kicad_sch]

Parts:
C28, C32: 10uF; C_0603_1608Metric
C29: 10u; C_0603_1608Metric
C30: 2u2; C_0603_1608Metric
C31: 100u; C_0603_1608Metric
C33: 3.3 nF; C_0603_1608Metric
C34: 22uF; C_0603_1608Metric
C35: 1uF; C_0603_1608Metric
C36: 1u; C_0603_1608Metric
D19, D20, D23: PMEG6020ER; Nexperia_CFP3_SOD-123W
D21, D22: LED; LED_0603_1608Metric
J10: Conn_01x02_Pin; JST_PH_B2B-PH-K_1x02_P2.00mm_Vertical
L2: SLF7055T-6R8N2R8-3PF; L_7.3x7.3_H4.5; PARTREV N/A
Q2: DMG2301L; SOT-23
R40, R41, R43, R45: 100k; R_0603_1608Metric
R42: 430k; R_0603_1608Metric
R44: 350k; R_0603_1608Metric
R46: 100; R_0603_1608Metric
R47: 330; R_0603_1608Metric
U9: TPS82130; Texas_SIL0008D_MicroSiP-8-1EP_2.8x3mm_P0.65mm_EP1.1x1.9mm_T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
U13: LTC4412xS6; TSOT-23-6
U14: TPS61092; Texas_RSA_VQFN-16-1EP_4x4mm_P0.65mm_EP2.7x2.7mm_ThermalVias
U15: AP2112K-3.3; SOT-23-5

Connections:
+3.3V: C36.1, R47.1, U15.5 (VOUT); also elsewhere on the board
+5V: D20.1 (K), D23.2 (A); also elsewhere on the board
GND: C28.2, C29.2, C30.2, C31.2, C32.2, C33.2, C34.2, C35.2, C36.2, D21.1 (K), D22.1 (K), J10.2, R41.2, R43.2, R45.2, U9.3 (GND), U9.9 (GND), U13.2 (GND), U13.3 (CTL), U14.5 (PGND), U14.6 (PGND), U14.7 (PGND), U14.10 (SYNC), U14.13 (GND), U14.17 (PAD), U15.2 (GND); also elsewhere on the board
unnamed: D21.2 (A), R46.2
unnamed: D22.2 (A), R47.2
unnamed: C32.1, D23.1 (K), U9.1 (EN), U9.2 (VIN)
unnamed: C29.1, J10.1, L2.1, R40.1, U14.8 (VBAT), U14.11 (EN)
unnamed: L2.2, U14.3 (SW), U14.4 (SW)
unnamed: Q2.1 (G), U13.5 (GATE)
unnamed: R44.2, R45.1, U9.6 (FB)
unnamed: C33.1, U9.8 (SS/TR)
unnamed: R42.2, R43.1, U14.14 (FB)
unnamed: R40.2, R41.1, U14.9 (LBI)
unnamed: C34.1, C35.1, R44.1, R46.1, U9.4 (VOUT), U9.5 (VOUT), U15.1 (VIN), U15.3 (EN)
POWAAAA: C28.1, D19.1 (K), D20.2 (A), Q2.2 (S), U13.6 (SENSE)
VBUS: D19.2 (A); also elsewhere on the board
bat: C30.1, C31.1, Q2.3 (D), R42.1, U13.1 (VIN), U14.1 (VOUT), U14.15 (VOUT), U14.16 (VOUT)

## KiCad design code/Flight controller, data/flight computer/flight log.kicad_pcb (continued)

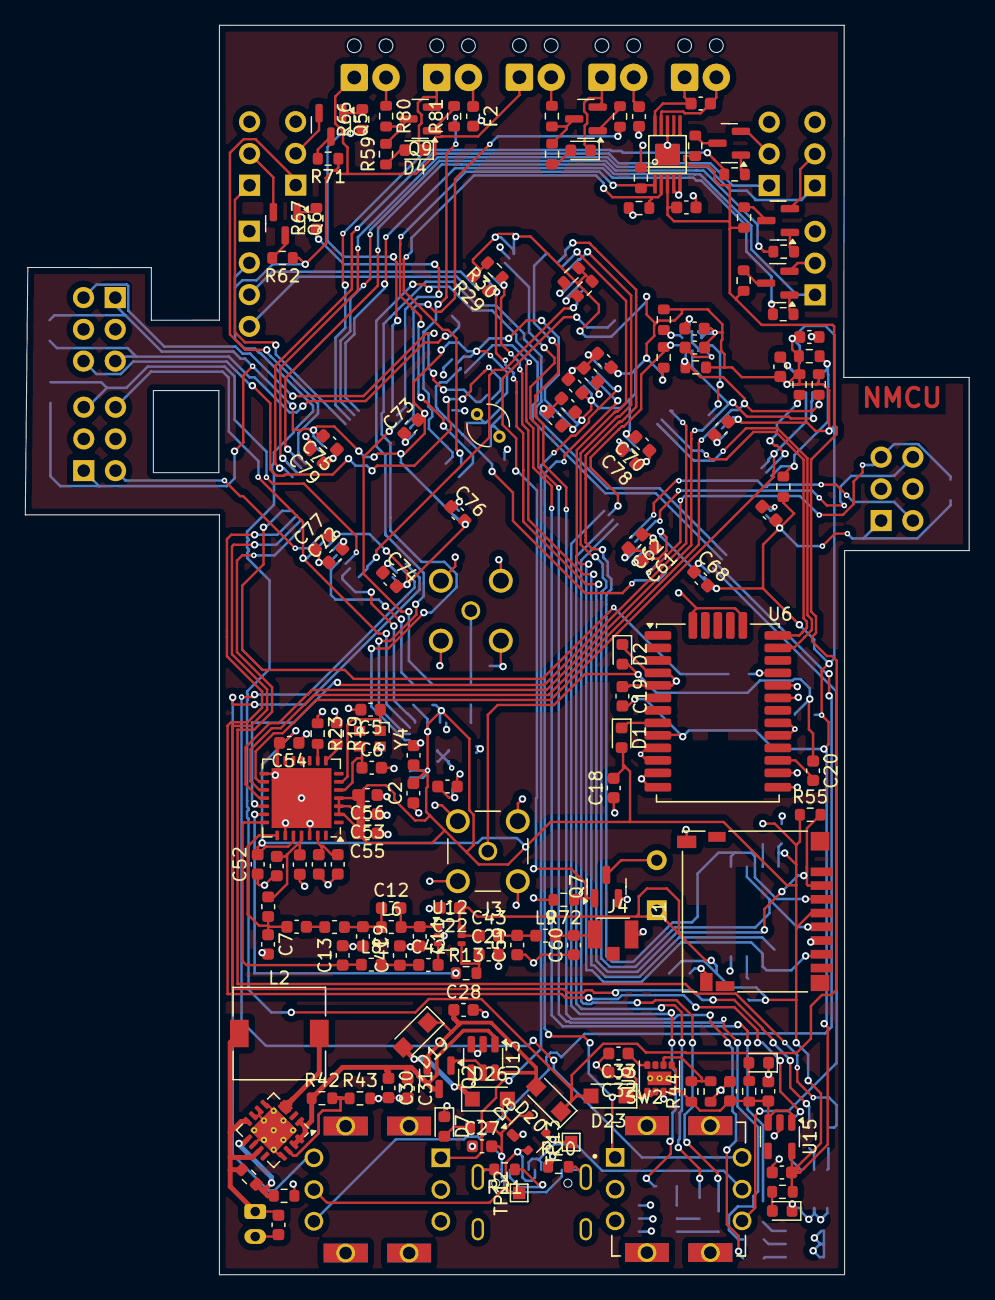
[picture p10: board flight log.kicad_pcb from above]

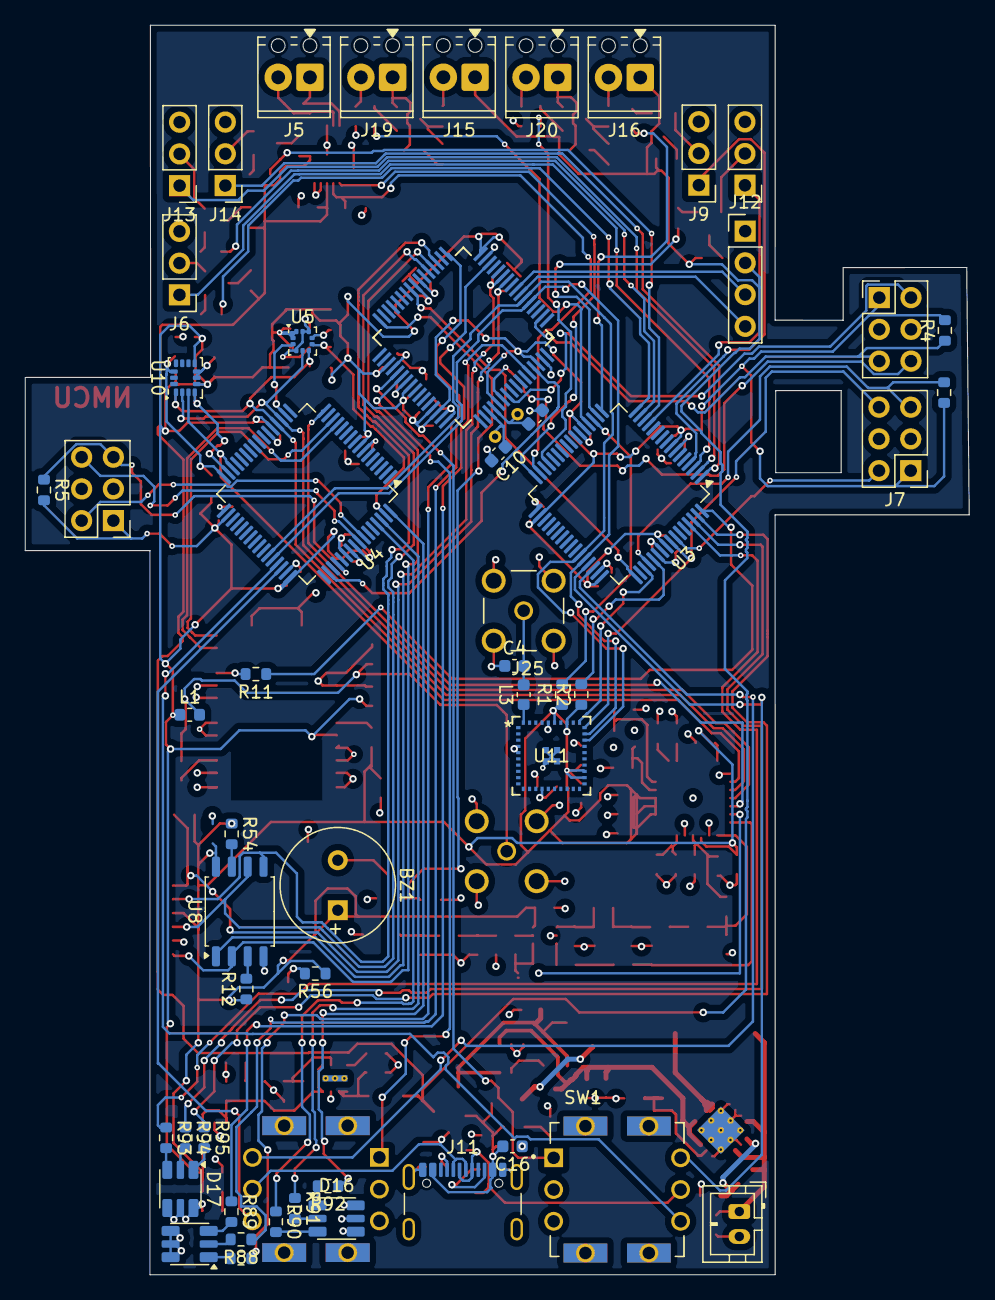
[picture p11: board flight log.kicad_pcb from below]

Board: 4 copper layers, 75.5 x 100.0 mm, 208 parts (53 on the bottom side), 164 nets.

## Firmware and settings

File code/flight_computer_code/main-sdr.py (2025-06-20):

import os
import subprocess
import time

def write_sweep_number(sweep_number):
    try:
        with open("last_sweep_number.txt", "w") as f:
            f.write(str(sweep_number))
    except Exception as e:
        print(f"Error writing sweep number: {e}")


def run_sweep(currrent_sweep_number):
    # Parameters
    start_freq = 30_000_000       # 24 MHz
    end_freq = 1_500_000_000      # 1.5 GHz
    step_freq = 2_000_000         # 2.4 MHz (max sample rate of RTL-SDR)
    sample_rate = 2_400_000       # 2.4 MSPS
    duration_sec = 0.07            # 100 ms
    samples = int(sample_rate * duration_sec)
    gain = 0                  # Adjust as needed TODO: ADJUST GAIN TO SEE NOISE FLOOR BETTER 30
    output_dir = "iq_data"
    os.makedirs(output_dir, exist_ok=True)

    print(f"Starting sweep {currrent_sweep_number} from {start_freq / 1_000_000:.3f} MHz to {end_freq / 1_000_000:.3f} MHz with step {step_freq / 1_000_000:.3f} MHz")


    for freq in range(start_freq, end_freq + 1, step_freq):
        out_file = os.path.join(output_dir, f"iq_{currrent_sweep_number}_{freq//1_000_000}MHz.iq")
        print(f"Capturing {freq / 1_000_000:.3f} MHz -> {out_file}")

        cmd = [
            "rtl_sdr",
            "-f", str(freq),
            "-s", str(sample_rate),
            "-n", str(samples),
            "-g", str(gain),
            out_file
        ]

        try:
            subprocess.run(cmd, check=True, timeout=5)
            print(f"Successfully captured {freq / 1_000_000:.3f} MHz")
        except Exception as e:
            print(f"rtl_sdr failed at {freq} Hz: {e}")
            time.sleep(2)  # Add a longer delay after failure


        time.sleep(0.1)  # Optional delay between captures

    print("Sweep complete.")

def get_current_sweep_number():
    try:
        with open("last_sweep_number.txt", "r") as f:
            last_sweep_number = f.read().strip()
        if not last_sweep_number:
            last_sweep_number = 0
        return int(last_sweep_number)
    except Exception as e:
        print(f"Error reading last sweep number: {e}")
        return 0

def get_uptime():
    try:
        with open("/proc/uptime", "r") as uptime_file:
            uptime = uptime_file.read().strip()
        return uptime.split()[0]  # Return the first part which is the uptime in seconds
    except Exception as e:
        print(f"Error reading uptime: {e}")
        return 3737

def log_sweep_number_uptime(sweep_number, uptime):
    try:
        with open("sweep_log.txt", "a") as log_file:
            log_file.write(f"Sweep Number: {sweep_number}, Uptime: {uptime} seconds\n")
    except Exception as e:
        print(f"Error logging sweep number and uptime: {e}")



current_sn = get_current_sweep_number()

new_sweep_number = get_current_sweep_number() + 1
write_sweep_number(new_sweep_number) 

run_sweep(current_sn)  # Initial sweep to start with
print("ran sdr sweep number: ", current_sn)
log_sweep_number_uptime(current_sn, get_uptime())



interval_seconds = 3 * 60  # Run sweeps every 100 seconds
while True:
    for i in range(0, interval_seconds):  
        time.sleep(1)  
    current_sn = get_current_sweep_number()
    print(f"Running sweep number: {current_sn} uptime: {get_uptime()} seconds")
    log_sweep_number_uptime(get_current_sweep_number(), get_uptime())
    new_sweep_number = get_current_sweep_number() + 1
    write_sweep_number(new_sweep_number) 
    try:
        run_sweep(current_sn)  # Run the sweep
        print("ran sweep...") 
    except Exception as e:
        print(f"Error during sweep: {e}")
        
    
    

    
    print(f"Sweep completed. Uptime: {get_uptime()} seconds") 
    

    
    
    

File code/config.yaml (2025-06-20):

# start of Meshtastic configure yaml
channel_url: https://meshtastic.org/e/#CgQ6AggNEhkIARiY8gEgDCgIOAFAA0gBUBVgAWgByAYB
config:
  bluetooth:
    enabled: true
    fixedPin: 123456
  device:
    nodeInfoBroadcastSecs: 10800
    rebroadcastMode: NONE
  display:
    screenOnSecs: 600
  lora:
    bandwidth: 31000
    codingRate: 8
    configOkToMqtt: true
    hopLimit: 3
    overrideDutyCycle: true
    region: US
    spreadFactor: 12
    sx126xRxBoostedGain: true
    txEnabled: true
    txPower: 21
    usePreset: true
  network:
    enabledProtocols: 1
    ntpServer: meshtastic.pool.ntp.org
  position:
    broadcastSmartMinimumDistance: 100
    broadcastSmartMinimumIntervalSecs: 30
    gpsUpdateInterval: 120
    positionBroadcastSecs: 900
    positionBroadcastSmartEnabled: true
    positionFlags: 811
  power:
    lsSecs: 300
    minWakeSecs: 10
    sdsSecs: 4294967295
    waitBluetoothSecs: 60
  security:
    privateKey: base64:gK+mmukY92XhgTHhsRhO8Ot0sYQu1n4G76/RptIvMUs=
    publicKey: base64:TiQuy1qm5v2zisGcTzMxlCBi4n7b2kcP2qEQO15Xjm0=
    serialEnabled: true
module_config:
  ambientLighting:
    blue: 56
    current: 10
    green: 87
    red: 61
  detectionSensor:
    detectionTriggerType: LOGIC_HIGH
    minimumBroadcastSecs: 45
  mqtt:
    address: mqtt.meshtastic.org
    encryptionEnabled: true
    password: large4cats
    root: msh/US
    username: meshdev
owner: with screen protector
owner_short: wsp

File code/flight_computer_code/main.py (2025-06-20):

import meshtastic.serial_interface
import time
from telemetry import Telemetry
import subprocess

run = True
meshdevice = "/dev/ttyUSB0"  # Adjust this to your Meshtastic device path 
mesh_node = meshtastic.serial_interface.SerialInterface(meshdevice)
mesh_node.frequency = int(915.5e6)  # Set frequency to 915 MHz, adjust as needed
print("\nConnected to Meshtastic interface\n")
#change frequency






def send_message(message):
    mesh_node.sendData(
        text=message,
        wantAck=False # CHECK REGION SETTINGS AND ADJUST FOR NOSE TOLERANCE
        
        )


packet_number = 0
while run == True:

    packet_number+=1
    if packet_number > 127:
        packet_number = 0
    telemetry = Telemetry()
    
    
    telemetry.gps_connection_port = "/dev/ttyS2"  # Adjust port as needed

    try:
        telemetry.update_telemetry()
    except Exception as e:
        print(f"Error updating telemetry: {e}")
    try:
        telemetry_data = telemetry.get_telemetry(packet_number=packet_number)
    except Exception as e:
        print(f"Error getting telemetry data: {e}")

    
    try:
        
        telemetry_bytes = bytes.fromhex(telemetry_data)
        
        mesh_node.sendData(
            data=telemetry_bytes,  # Send bytes instead of hex string
            wantAck=False,
            portNum=1,
            priority=64
        )
        print(telemetry_bytes)
        print("Raw packed bytes:", [hex(b) for b in telemetry_bytes])
        print("Hex string:", telemetry_data)
        
    except Exception as e:
        print(f"Error sending telemetry message attempting reconnection: {e}")
        mesh_node.close()
        mesh_node = meshtastic.serial_interface.SerialInterface(meshdevice)
        print("Reconnected to Meshtastic interface\n")

    time.sleep(15)  # Adjust sleep time as needed


mesh_node.close()
exit(0)

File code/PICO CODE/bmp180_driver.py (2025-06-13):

# bmp180_driver.py

import time
import struct

class BMP180:
    def __init__(self, i2c, addr=0x77):
        self.i2c = i2c
        self.addr = addr
        self._read_calibration()

    def _read_calibration(self):
        def readS16(reg):
            d = self.i2c.readfrom_mem(self.addr, reg, 2)
            return struct.unpack('>h', d)[0]

        def readU16(reg):
            d = self.i2c.readfrom_mem(self.addr, reg, 2)
            return struct.unpack('>H', d)[0]

        self.AC1 = readS16(0xAA)
        self.AC2 = readS16(0xAC)
        self.AC3 = readS16(0xAE)
        self.AC4 = readU16(0xB0)
        self.AC5 = readU16(0xB2)
        self.AC6 = readU16(0xB4)
        self.B1  = readS16(0xB6)
        self.B2  = readS16(0xB8)
        self.MB  = readS16(0xBA)
        self.MC  = readS16(0xBC)
        self.MD  = readS16(0xBE)

    def read_temperature(self):
        self.i2c.writeto_mem(self.addr, 0xF4, b'\x2E')
        time.sleep_ms(5)
        d = self.i2c.readfrom_mem(self.addr, 0xF6, 2)
        UT = struct.unpack('>H', d)[0]

        X1 = ((UT - self.AC6) * self.AC5) >> 15
        X2 = (self.MC << 11) // (X1 + self.MD)
        B5 = X1 + X2
        self.B5 = B5
        return ((B5 + 8) >> 4) / 10

    def read_pressure(self):
        self.i2c.writeto_mem(self.addr, 0xF4, b'\x34')
        time.sleep_ms(8)
        d = self.i2c.readfrom_mem(self.addr, 0xF6, 3)
        UP = ((d[0] << 16) + (d[1] << 8) + d[2]) >> 8

        B6 = self.B5 - 4000
        X1 = (self.B2 * ((B6 * B6) >> 12)) >> 11
        X2 = (self.AC2 * B6) >> 11
        X3 = X1 + X2
        B3 = (((self.AC1 * 4 + X3) << 0) + 2) >> 2

        X1 = (self.AC3 * B6) >> 13
        X2 = (self.B1 * ((B6 * B6) >> 12)) >> 16
        X3 = ((X1 + X2) + 2) >> 2
        B4 = (self.AC4 * (X3 + 32768)) >> 15
        B7 = (UP - B3) * 50000
        if B7 < 0x80000000:
            p = (B7 << 1) // B4
        else:
            p = (B7 // B4) << 1
        X1 = (p >> 8) * (p >> 8)
        X1 = (X1 * 3038) >> 16
        X2 = (-7357 * p) >> 16
        return p + ((X1 + X2 + 3791) >> 4)

    def read_altitude(self, sea_level_pressure=101325.0):
        p = self.read_pressure()
        return 44330.0 * (1.0 - pow(p / sea_level_pressure, 0.1903))

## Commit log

2025-06-06 pcb files
    [flight log.kicad_pcb, flight log.kicad_sch, power.kicad_sch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]
2025-06-08 flight computer work + testing uart meshtastic node connection
2025-06-10 should fix no gps crash
    [main.py, telemetry.py]
2025-06-12 BMP180 testing and drivers
2025-06-16 fixed the numbers not iterating
    [main-sdr.py]
2025-06-17 adjusted gain in case i forget later
2025-06-17 updated to add sensor telemetry
2025-06-17 battery voltage working now fix bug i think
    [main.py, telemetry.py]
2025-06-18 updated pico port
2025-06-18 fixed sdr not stating imidiately
    [main-sdr.py]
